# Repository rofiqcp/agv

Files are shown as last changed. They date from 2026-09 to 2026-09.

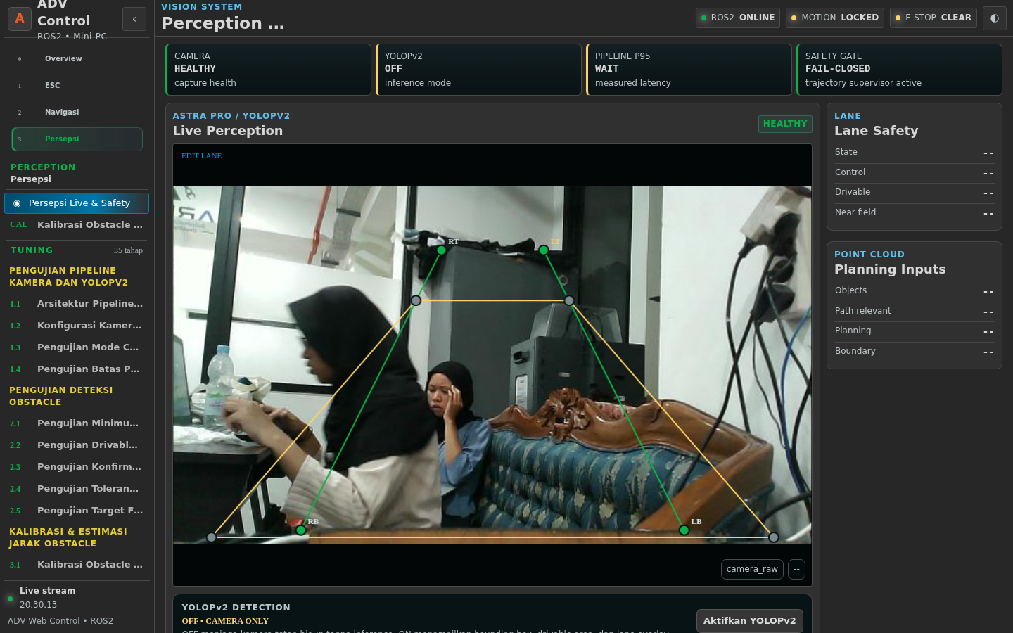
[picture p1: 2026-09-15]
.ui_audit/audit-perception-desktop.png

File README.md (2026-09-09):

# AGV ROS 2 Workspace

Workspace ROS 2 Humble untuk Autonomous Ground Vehicle Ackermann. Root project selalu memakai `AGV_ROOT`; default portable-nya adalah `$HOME/agv`, sehingga username Linux boleh berbeda tanpa mengubah source.

## 1. Clone Pertama Kali

```bash
git clone --recurse-submodules -b v1 https://github.com/rofiqcp/agv.git "$HOME/agv"
cd "$HOME/agv"
git submodule update --init --recursive
```

Jika repository sudah ada:

```bash
cd "$HOME/agv"
git pull --ff-only
git submodule update --init --recursive
```

Firmware STM32F103 berada pada Git submodule `hoverboard-vesc`, sedangkan firmware STM32F411 HMI/gateway berada pada submodule `F4gateway`. Repository AGV mem-pin commit keduanya agar versi hardware reproducible.

## 2. Instalasi Otomatis

Entry point instalasi adalah `install.sh`. Script ini idempotent dan boleh dijalankan ulang.
```bash
cd "$HOME/agv"
./install.sh --with-model --with-browser-qa
```

Default build installer dibatasi untuk menjaga NUC/PC lain tetap responsif:

- CPU maksimal 50% mesin.
- RAM build maksimal 50% RAM fisik.
- `Release` build.
- Compile `j1` untuk translation unit LibTorch/Qt yang berat.
- Package dibuild dari `src/` saja agar repository referensi/submodule tidak dipindai sebagai package ROS.

Opsi penting:

```bash
./install.sh --no-build
./install.sh --build-percent 50 --memory-percent 50
./install.sh --with-model
./install.sh --with-browser-qa
```

Installer memasang dependency ROS/system/Python, `rosdep`, PlatformIO, model opsional, browser QA opsional, dan managed environment block ke `~/.bashrc`.

## 3. Environment Shell
Setelah installer selesai, buka shell baru atau jalankan:

```bash
source ~/.bashrc
```

Managed block AGV menetapkan dan men-source environment berikut:

```text
AGV_ROOT=$HOME/agv
ROS_DISTRO=humble
ROS_DOMAIN_ID=42
```

`$AGV_ROOT/scripts/agv_env.sh` otomatis source `/opt/ros/humble/setup.bash` dan `$AGV_ROOT/install/setup.bash` bila tersedia. Karena itu command ROS dapat dijalankan dari direktori mana pun.

Verifikasi:

```bash
cd /tmp
echo "$AGV_ROOT"
echo "$ROS_DOMAIN_ID"
ros2 pkg prefix navigation
ros2 pkg prefix esc
command -v ros2
```

## 4. Struktur Utama

```text
agv/
├── src/navigation/   # Nav2, localization, EKF, ROS Web, calibration
├── src/perception/   # Astra Pro + YOLOPv2 CPU/GPU
├── src/esc/          # Ackermann command mux + VESC bridge
├── src/stmf4/        # Bridge Mini-PC ↔ STM32F411 ↔ GNSS/VESC
├── hoverboard-vesc/  # Git submodule firmware STM32F103 dual FOC
├── F4gateway/        # Git submodule firmware STM32F411 HMI/gateway
├── models/           # Model YOLOPv2 dan downloader
├── scripts/          # Environment, portability check, browser QA
├── install.sh
└── README.md
```

Folder `build/`, `install/`, dan `log/` adalah hasil lokal dan tidak menjadi source authority.

## 5. Model YOLOPv2

Jika belum memakai `--with-model`:

```bash
cd "$AGV_ROOT/models"
./model.sh
```

Model CPU default:

```text
$AGV_ROOT/models/yolopv2.pt
```

Override path bila diperlukan menggunakan environment `YOLOPV2_PT_PATH` atau `YOLOP_ENGINE_PATH`; source tidak boleh memakai hardcoded `/home/<user>/...`.

## 6. Build dan Test
Gunakan installer untuk build resource-limited yang aman:

```bash
cd "$AGV_ROOT"
./install.sh --build-percent 50 --memory-percent 50
```

Atau untuk incremental build manual setelah environment aktif:

```bash
cd "$AGV_ROOT"
colcon build --base-paths src --symlink-install --executor sequential \
  --allow-overriding perception --cmake-args -DCMAKE_BUILD_TYPE=Release
```

Setelah build:

```bash
source "$AGV_ROOT/install/setup.bash"
colcon test --base-paths src --executor sequential
colcon test-result --verbose
```

Target project adalah 0 warning/error build dan 0 failure test. Portability contract juga dapat dijalankan langsung:

```bash
python3 "$AGV_ROOT/scripts/check_portable_paths.py"
```

## 7. Menjalankan Autonomous Stack
Dari direktori mana pun setelah `source ~/.bashrc`:

```bash
ros2 launch navigation autonomous.launch.py
```

Simpan log runtime:

```bash
ros2 launch navigation autonomous.launch.py | tee "$AGV_ROOT/log/$(date +%Y%m%d_%H%M%S).txt"
```

Untuk QA tanpa risiko command gerak gunakan mode read-only:

```bash
ros2 launch navigation autonomous.launch.py \
  mode:=web web_read_only:=true enable_rviz:=false \
  enable_joystick:=false enable_keyboard:=false
```

ROS Web tersedia di `http://127.0.0.1:5000`.

## 8. Browser QA Playwright

Install sekali lewat:

```bash
cd "$AGV_ROOT"
./install.sh --no-build --with-browser-qa
```

Dengan runtime read-only aktif, jalankan:
```bash
cd "$AGV_ROOT"
node scripts/qa_ros_web_playwright.js
```

QA memeriksa:

- HTTP 200 dan SSE live.
- Tidak ada console/page error.
- Tidak ada HTTP 4xx/5xx atau request failure.
- Tidak ada POST otomatis saat backend read-only.
- Map Navigation terlihat.
- Dua grafik ESC terlihat.
- Frame kamera valid.
- Configuration dan Test workspace dapat dibuka.
- Data Health terisi.
- Layout mobile tidak overflow horizontal.

## 9. Git dan Submodule

Branch utama AGV adalah `v1`. Perubahan firmware harus di-commit/push di repository firmware terlebih dahulu, lalu pointer submodule di repository AGV diperbarui.

```bash
cd "$AGV_ROOT/hoverboard-vesc"
git status
# commit/push STM32F103 bila ada perubahan

cd "$AGV_ROOT/F4gateway"
pio run
git status
# commit/push STM32F411 ke branch v1

cd "$AGV_ROOT"
git add hoverboard-vesc F4gateway .gitmodules
git commit -m "chore: sync firmware submodules"
```

Untuk mengambil commit firmware yang dipin oleh branch AGV saat ini:

```bash
git pull --ff-only
git submodule sync --recursive
git submodule update --init --recursive
```

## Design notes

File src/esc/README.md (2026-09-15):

# ESC Integrated Runtime

Package `esc` sekarang hanya memiliki dua runtime C++:

1. `motor_teleop` — keyboard/gamepad global -> `/cmd_vel/teleop`
2. `esc_ackermann` (`ackermann_controller_server.cpp`) — mux + Ackermann + UART STM

## Priority

1. E-STOP / safety
2. TELEOP active
3. TELEOP release hold (zero command, default 0.50 s)
4. NAV2 final command (`/cmd_vel` by default)
5. IDLE zero

Teleop yang idle terus publish zero **tidak** mengambil alih Nav2 karena ownership manual ditentukan juga oleh `/teleop/active_source`.

## Command chain

```text
keyboard/gamepad -> motor_teleop -> /cmd_vel/teleop ----+
                                                       |
Nav2 controller -> /cmd_vel_nav_raw                    |
 -> velocity_smoother -> /cmd_vel_nav_smoothed         |
 -> NavigationCore/perception/collision -> /cmd_vel ---+-> esc_ackermann
                                                           | mux
                                                           | Ackermann conversion
                                                           | robust UART
                                                           v
                                                          STM32
```

Untuk memakai smoother langsung (bypass final NavigationCore/CollisionMonitor), ubah `nav2_topic` di `config/ackermann.yaml` menjadi `/cmd_vel_nav_smoothed`. Default `/cmd_vel` lebih aman karena merupakan command final setelah safety/collision pipeline.

## Single source of truth limits

`config/teleop.yaml`:

- `speed_max: 1.00` m/s
- `yaw_max_deg_s: 80.0`
- `serial_left_max_deg: 90.0` logical/protocol steering limit (physical wheel angle must be calibrated separately)
- `serial_right_max_rpm: 300.0`

Mapping drive: `1.0 m/s -> 300 RPM`, `0.5 -> 150 RPM`, `-1.0 -> -300 RPM`.

Manual steering preserves the previous teleop behavior: full A/D at the current yaw limit maps to the same real steering degree. Nav2 uses true Ackermann conversion `delta = atan(L * omega / v)` and is then clamped to the same real steering limit.

## STM serial contract

This ROS package expects the robust hoverboard protocol already integrated previously:

- 921600 8N1
- fixed 14-byte frame
- SOF `A5 5A`
- sequence number
- CRC16-CCITT
- command: LEFT real centi-degree + RIGHT deci-RPM
- ACK: measured LEFT real angle + measured RIGHT RPM + status
- firmware watchdog 250 ms

Only `esc_ackermann` opens the serial port. `motor_teleop` contains no UART sender.

## Build

```bash
cd $AGV_ROOT
source /opt/ros/humble/setup.bash
colcon build --symlink-install --packages-select esc navigation
source install/setup.bash
```

Standalone ESC runtime:

```bash
# Default runtime: Mini-PC -> dedicated CH340 USB-UART -> STM32F103/VESC directly.
# F411 remains HMI/GNSS only and never transports actuator bytes.
# VESC Tool desktop connects to localhost TCP 127.0.0.1:65102 through
# vesc_tool_bridge; Web and desktop tooling share the same maintenance authority.
# Nomor /dev/ttyUSBx tidak pernah menjadi authority otomatis.
ros2 launch esc esc.launch.py

# Override hanya untuk commissioning/debug yang disengaja:
# ros2 launch esc esc.launch.py serial_device:=/dev/serial/by-id/<ESC_ID>
```

Full autonomous runtime remains through `navigation/launch/autonomous.launch.py`.

## Steering physical calibration (V10 Part 1)

Nilai protocol STM `-90/0/+90` **bukan** sudut roda fisik. Gunakan halaman **Kalibrasi Steering Fisik** pada GUI navigation untuk menangkap LEFT/CENTER/RIGHT protocol+ACK dan memasukkan hasil ukur sudut roda dalam kiri/kanan. Setelah aktif, `/esc/steering_actual` dan odometri Ackermann menggunakan sudut roda nyata. `serial_left_max_deg` dipertahankan hanya sebagai fallback legacy sebelum commissioning fisik selesai.

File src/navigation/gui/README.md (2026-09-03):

# Autonomous Vehicle Interface — Native C++/Qt5

GUI operator package `navigation` sekarang sepenuhnya native **C++17 + Qt5 + rclcpp**. GUI lama `agv_gui.py` sudah tidak menjadi runtime dan tidak lagi membutuhkan `rclpy` atau `PyQt5`.

## Build

```bash
cd ~/Sistem-Otomasi-Car/Car-MiniPC/ros
rm -rf build/navigation install/navigation
colcon build --packages-select navigation --symlink-install --cmake-clean-cache --event-handlers console_direct+
source install/setup.bash
```

Dependency native yang diperlukan antara lain Qt5 Widgets/Network, yaml-cpp, serta library RViz2 (`rviz_common`, `rviz_rendering`, dan `rviz_default_plugins`). Pada Ubuntu 22.04 + ROS 2 Humble, instalasi `ros-humble-desktop` sudah menyediakannya. Dengan rosdep:

```bash
rosdep install --from-paths src --ignore-src -r -y
```

Jalankan seluruh stack + GUI:

```bash
ros2 launch navigation gui.launch.py
```

GUI saja:

```bash
ros2 run navigation agv_gui
```

## Struktur

- `agv_gui.cpp` — entry translation unit, rclcpp bridge, dan Qt meta-object classes.
- `modules/*.cpp` — modul GUI terpisah untuk YAML/core, reporting, acquisition, steering, ESC/map, kamera, dan main window.
- `agv_gui_specs.hpp` — definisi parameter/configuration pages.
- `agv_experiment_catalog.hpp` — satu-satunya katalog subbab pengujian 4.x untuk Navigasi, Persepsi, dan ESC/FOC.
- `assets/` — aset visual.

ROS dijalankan pada `MultiThreadedExecutor` terpisah sehingga callback sensor tidak memblokir event-loop Qt. Data callback diteruskan ke Qt melalui signal/slot queued connection. Subscription disimpan selama umur bridge sehingga tidak terhapus setelah dibuat.

## Navigasi GUI

Tombol `NAV2 MAP` di kiri atas, tepat di samping `OVERVIEW`, membuka visualisasi Nav2 di panel tengah GUI. Subtab `NAV2 LIVE` menampilkan `/map`, URDF kendaraan, Goal Pose, global path Smac Hybrid-A*, transformed plan MPPI, footprint, dan kandidat trajectory MPPI. Subtab `GROUND TRUTH` mempertahankan kanvas PGM/OSM, tabel target, dan akuisisi ground truth lama.

Renderer RViz/OGRE dibuat secara lazy saat `NAV2 MAP` dibuka dan dihentikan saat halaman ditinggalkan. Global/local costmap default OFF karena map UNDIP besar; operator dapat mengaktifkannya dari checkbox. Kandidat MPPI tetap aktif dengan sampling visual 1/20 rollout, tanpa mengubah 1000 sampel optimasi controller.

Tombol `☰` kiri atas membuka **satu floating menu**. Menu hanya mempunyai tiga tab utama: **Navigasi**, **Persepsi**, dan **ESC**. Di setiap tab, subbab 4.1, 4.2, dst. serta leaf 4.x.x dibangun langsung dari `agv_experiment_catalog.hpp`. Tidak ada lagi panel `Tools lama` dan tidak ada tree BAB IV permanen yang memenuhi sidebar.

Klik leaf 4.x.x merutekan ke workspace akuisisi existing yang sama, bukan membuat widget duplikat. Pilihan subsystem/leaf terakhir disimpan ke `gui.yaml` (`navigation_menu.active_subsystem` dan `navigation_menu.active_leaf`) sehingga session berikutnya kembali ke pengujian terakhir.

Parameter panel kiri tetap memakai YAML sebagai source of truth dengan autosave atomik. GUI juga mempertahankan vehicle-authority synchronization, Config-vs-Runtime audit, MPPI A/B/C sweep, stationary IMU/GNSS capture, COG qualification, GNSS fusion controls, rosbag, CPU/GPU profile, snapshot konfigurasi, CSV/PNG export, dan metadata SHA-256.

## Pelaporan

Setiap CSV menghasilkan sidecar `.meta.json` yang berisi session/experiment metadata, snapshot SHA-256 konfigurasi, serta statistik numerik. Kolom bernama `error` atau `residual` juga mendapatkan RMSE, mean absolute error, dan maximum absolute error.

## Catatan runtime

Perubahan YAML tidak otomatis berarti node yang sudah berjalan telah menerima nilai baru. Gunakan **Verify Runtime** dan restart/live-apply node terkait sebelum merekam pengujian. Tutup GUI akan menghentikan launch pada `gui.launch.py`, sehingga autonomous stack tidak tertinggal berjalan tanpa HMI.

Panduan visual, topik, penggunaan Goal Pose, dan diagnosis tersedia di `docs/GUI_NAV2_EMBEDDED.md`.

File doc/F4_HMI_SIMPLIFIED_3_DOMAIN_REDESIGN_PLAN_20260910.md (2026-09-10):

# F4 HMI Simplified 3-Domain Redesign Plan

Tanggal: 2026-09-10
Target: STM32F411 + ILI9341 320x240 + XPT2046
Sumber data: `/home/sirobo/agv/src`, `/home/sirobo/agv/F4gateway`, `/home/sirobo/agv/hoverboard-vesc`

## 1. Tujuan

Redesain HMI menjadi sederhana untuk operator, tetapi tetap kuat untuk commissioning dan diagnostics.
Menu utama hanya berisi HOME, ESC, PERSEPSI, dan NAVIGASI.
SYSTEM tidak tampil sebagai menu utama; health penting tetap terlihat sebagai indikator global.
Diagnostics teknis dipertahankan melalui Service Mode agar tidak ada fungsi yang hilang.

Prinsip utama:
- satu layar = satu tujuan;
- maksimal tiga kartu besar per halaman;
- BACK / LEFT / RIGHT selalu pada posisi yang sama;
- icon + label wajib pada setiap kartu;
- data live hanya yang membantu keputusan operator;
- parameter berbahaya tidak diedit langsung dari layar umum;
- test motion menggunakan hold-to-run + release-to-stop;
- stale/offline/fault harus terlihat jelas.

## 2. Hierarki layar

```text
SPLASH
  -> HOME
      -> MAIN MENU
          -> ESC
          -> PERCEPTION
          -> NAVIGATION
```
## 3. HOME

HOME tidak menjadi menu; HOME adalah ringkasan kendaraan.
Hanya tiga data utama ditampilkan besar:
1. SPEED — `speedKmh` / `driveActualMps`.
2. VEHICLE STATE — READY / STOPPED / RUNNING / FAULT, dengan E-STOP override merah.
3. POWER / VBUS — tegangan supply/VESC bus dan warning undervoltage/overvoltage.

Tambahan kecil yang tidak dianggap kartu data:
- chip kecil AUTO/MANUAL + active source;
- indikator ESC, PER, NAV berupa tiga dot kecil READY/WARN/FAULT;
- indikator link F4↔ROS dan F4↔F103 kecil;
- jam/data age tidak perlu memenuhi layar.

Interaksi HOME:
- hanya satu tombol besar `MENU` di bawah;
- tidak ada carousel;
- tidak ada tombol setting;
- E-STOP selalu menjadi banner prioritas tertinggi.

Acceptance HOME:
- dapat dibaca <1 detik;
- tidak lebih dari tiga angka/status besar;
- operator langsung tahu: bergerak seberapa cepat, kendaraan dalam state apa, dan power supply sehat atau tidak.

## 4. MAIN MENU

Header: tombol `HOME` di kiri atas.
Isi: tiga kartu besar penuh lebar efektif:
- ESC — steering wheel + bolt;
- PERSEPSI — camera/eye;
- NAVIGASI — route/map pin.

Tidak ada SYSTEM card pada menu utama.
## 5. Layout standar domain

Setiap root ESC / PERSEPSI / NAVIGASI memakai layout identik.

Top navigation bar sekitar 34 px:
- kiri: `BACK`;
- tengah: `LEFT`;
- kanan: `RIGHT`;
- judul domain kecil berada di antara/di bawah kontrol tanpa menambah tombol.

Area kartu dari sekitar y=48 sampai y=218:
- tiga kartu submenu berdampingan;
- setiap kartu sekitar 98x158 px efektif;
- icon besar di bagian atas;
- label 1–2 baris di bawah;
- status dot kecil pada pojok kartu: green/yellow/red/gray;
- page indicator kecil `1/3`, `2/3`, dst.

LEFT/RIGHT menggeser satu kelompok berisi tiga submenu, bukan satu card.
Wrap-around boleh diaktifkan: page terakhir RIGHT kembali ke page pertama.
BACK kembali satu level dan tidak mengubah state kendaraan.

## 6. Detail page standard

Ketika kartu dipilih, masuk ke detail page.
Detail page tetap memakai kontrol atas `BACK / LEFT / RIGHT`.
LEFT/RIGHT di detail berganti view data dalam fungsi yang sama.
Maksimal tiga metric primer besar per view.
Bar status tipis menampilkan freshness, source, dan fault.

Action/test hanya muncul bila memang tersedia dan aman.
Read-only menjadi default; edit/test harus eksplisit.
Parameter yang dapat menggerakkan aktuator menggunakan confirmation/gate dan dead-man.
## 7. ESC — struktur submenu

ESC dibuat 4 halaman, masing-masing tepat tiga kartu.

### ESC page 1/4 — operasi dasar
1. `ESC OVERVIEW`
2. `OPERATOR MODE`
3. `STEERING`

### ESC page 2/4 — aktuator dan FOC
4. `DRIVE`
5. `FOC / POWER`
6. `MOTOR TELEMETRY`

### ESC page 3/4 — sensor dan commissioning
7. `ENCODER`
8. `CALIBRATION`
9. `COMMUNICATION`

### ESC page 4/4 — robustness
10. `FAULT & SAFETY`
11. `PERFORMANCE`
12. `MANUAL TEST`

Semua kartu mempunyai icon berbeda dan status dot.
Tidak ada parameter tuning berbahaya langsung pada root card.
### 7.1 ESC OVERVIEW
View A — motion:
- vehicle speed;
- drive target vs actual;
- steering target vs actual.

View B — motor summary:
- right motor eRPM / mechanical RPM;
- VESC connected/fresh;
- current fault code.

View C — control readiness:
- ESC feedback valid;
- encoder ready;
- active command source: TELEOP / HMI / NAV2 / IDLE.

Tidak ada test pada overview.

### 7.2 OPERATOR MODE
Tampilan:
- current mode AUTO/MANUAL;
- active source;
- motion-ready gate;
- E-STOP / safety gate.

Action:
- ganti AUTO <-> MANUAL hanya ketika speed ~0 dan tidak E-STOP;
- perubahan membutuhkan ACK dari ROS bridge;
- timeout/failure harus mengembalikan nilai lama.
### 7.3 STEERING
View A — live:
- target angle deg;
- actual angle deg;
- tracking error deg.

View B — steering state:
- calibrated / homed / encoder synced;
- raw encoder / logical position;
- sensor/FOC mode.

View C — limits:
- physical left/right limit;
- operational limit;
- center/deadband state.

Safe test:
- selectable test angle 5–30 deg;
- HOLD LEFT / HOLD CENTER / HOLD RIGHT;
- release selalu STOP/HOLD;
- hanya MANUAL + zero speed + fresh encoder + no E-STOP.

### 7.4 DRIVE
View A — live:
- drive target m/s;
- drive actual m/s;
- eRPM / mechanical RPM.

View B — calibration:
- drive scale;
- eRPM per m/s;
- odometry calibration scale.
View C — drive safety:
- max commanded speed;
- watchdog state;
- perception/autonomy gate.

Safe test:
- manual speed selector 10–50%;
- HOLD FORWARD / HOLD REVERSE;
- release/slide-out -> current/RPM command zero;
- hard timeout tetap aktif di F4 dan F103.

### 7.5 FOC / POWER
View A — power:
- Vbus;
- motor current / input current;
- duty cycle.

View B — FOC current:
- Iq;
- Id;
- current limit.

View C — thermal/fault:
- MOS temperature;
- motor temperature bila tersedia;
- active VESC fault.

Data diambil dari VESC `COMM_GET_VALUES(_SELECTIVE)`.
F4 bridge perlu diperluas karena telemetry F4 saat ini belum membawa semua field ini.
Tidak ada direct current/duty test pada operator page.
### 7.6 MOTOR TELEMETRY
View A — LEFT steering motor:
- RPM/eRPM;
- position;
- duty/current.

View B — RIGHT drive motor:
- RPM/eRPM;
- Vbus/current;
- duty/fault.

View C — comparison:
- left/right fault state;
- link freshness;
- telemetry age.

### 7.7 ENCODER
View A — steering encoder:
- raw count;
- logical steering deg;
- synced/configured state.

View B — diagnostics:
- edge A / edge B count;
- invalid transition / error count;
- direction/inversion.

View C — rotor relationship:
- encoder mechanical angle;
- observer electrical angle;
- encoder-observer / PID error.

Read-only by default. Encoder detect/align hanya melalui commissioning gate.
### 7.8 CALIBRATION
View A — steering calibration summary:
- calibrated/homed;
- measured span / safe span;
- current center position.

View B — physical mapping:
- left physical reference;
- center reference;
- right physical reference.

View C — drive calibration:
- wheel radius;
- eRPM per m/s;
- odometry scale.

Action dibatasi:
- `HOME STEERING` dan `SET CENTER` hanya saat kendaraan idle;
- calibration wizard menggunakan langkah eksplisit dan confirmation;
- parameter raw FOC/ADC tidak diedit dari operator HMI.

### 7.9 COMMUNICATION
View A — F4↔F103:
- connected/fresh;
- UART RX/TX age;
- error/drop/recovery counters.

View B — ROS↔F4:
- HMI connected;
- command/telemetry age;
- deferred queue/drop state.

View C — maintenance ownership:
- RUNTIME / VESC TOOL / PYTHON owner;
- maintenance active;
- route transition/safe-stop state.
### 7.10 FAULT & SAFETY
View A — active faults:
- VESC fault code/text;
- E-STOP state;
- safety switch state.

View B — electrical limits:
- under/over-voltage status;
- over-current status;
- temperature limit status.

View C — command safety:
- command watchdog;
- active source freshness;
- autonomy/perception gate.

Action yang diizinkan hanya `CLEAR/ACK` bila fault memang recoverable.
Tidak ada bypass safety dari layar.

### 7.11 PERFORMANCE
View A — control timing:
- command loop rate;
- feedback age;
- max service latency.

View B — F103 realtime:
- ISR max/budget;
- GET_VALUES latency;
- watchdog/reset counters.

View C — F4 gateway:
- service p95/p99/max;
- stack headroom;
- SPI/UART error counters.

### 7.12 MANUAL TEST
Dedicated commissioning screen, bukan metric page biasa.
Controls: LEFT / FORWARD / STOP / RIGHT / REVERSE.
Speed dan steering-angle preset ditampilkan di layar.
Semua motion action harus hold-to-run; STOP immediate; release/timeout/freshness-loss menghasilkan STOP.
## 8. PERSEPSI — struktur submenu

PERSEPSI dibuat 3 halaman, masing-masing tiga kartu.

### PERSEPSI page 1/3 — sumber dan hasil utama
1. `PER OVERVIEW`
2. `CAMERA`
3. `DETECTION`

### PERSEPSI page 2/3 — pemahaman area kendaraan
4. `LANE`
5. `DRIVABLE AREA`
6. `OBSTACLE`

### PERSEPSI page 3/3 — kualitas dan commissioning
7. `PERFORMANCE`
8. `CALIBRATION`
9. `PER TEST`

F4 tidak perlu menampilkan video kamera penuh; bandwidth serial, RAM dan fungsi operator tidak membutuhkannya.
HMI menampilkan health/hasil perception yang actionable.

### 8.1 PER OVERVIEW
View A:
- camera connected/healthy;
- perception ready;
- inference ON/OFF.

View B:
- lane safety state;
- drivable clear/valid;
- obstacle detected + nearest distance.

View C:
- pipeline FPS;
- data freshness;
- control/advisory state.
### 8.2 CAMERA
View A — camera health:
- connected;
- healthy;
- current FPS.

View B — capture config summary:
- resolution;
- requested camera FPS;
- backend CPU/GPU / inference state.

View C — stream diagnostics:
- frame age;
- dropped/failed frame count bila tersedia;
- hotplug/recovery state.

Action aman:
- inference ON/OFF boleh melalui ACK;
- restart camera tidak ditempatkan sebagai tombol satu-tap; service confirmation diperlukan.

### 8.3 DETECTION
View A — nearest object:
- class;
- distance m;
- confidence.

View B — detection summary:
- number of objects;
- ROI-valid objects;
- nearest obstacle class/distance.

View C — tracking:
- active track count;
- missed/stale state;
- detection data age.

F4 bridge perlu ditambah field confidence/count bila belum tersedia.
### 8.4 LANE
View A — lane state:
- lane safety state;
- center offset;
- confidence.

View B — geometry:
- near/far lookahead;
- estimated road width;
- lane center correction.

View C — control:
- lane-control state;
- requested steering correction;
- command/data freshness.

### 8.5 DRIVABLE AREA
View A:
- valid / invalid;
- drivable clear / blocked;
- drivable fraction.

View B:
- nearest boundary/clearance;
- left/right usable corridor;
- far lookahead.

View C:
- lane constraint active;
- ROI/config status;
- source age.

Read-only untuk operator.

### 8.6 OBSTACLE
View A:
- nearest obstacle class;
- forward distance;
- lateral offset.

View B:
- blocked/clear state;
- number of obstacle points/tracks;
- ROI-valid state.
View C:
- confirm/release frame counters;
- obstacle data age;
- perception advisory output state.

### 8.7 PERFORMANCE
View A:
- pipeline FPS;
- inference latency ms;
- frame age.

View B:
- backend CPU/GPU;
- inference enabled;
- dropped/recovery count bila tersedia.

View C:
- publish/update rates;
- lane metric age;
- obstacle metric age.

### 8.8 CALIBRATION
View A — obstacle distance calibration:
- selected class/model;
- scale;
- bias.

View B — lane corridor calibration:
- camera height/pitch;
- left/right corridor offsets;
- safety margin.

View C — status:
- calibration source/version;
- saved/unsaved state;
- current ROI valid.

HMI operator hanya melihat summary. Parameter geometrik detail tetap di ROS Web karena lebih cocok untuk layar besar dan visual overlay.

### 8.9 PER TEST
Test yang aman:
- camera heartbeat test;
- inference ON/OFF test;
- lane freshness test;
- obstacle freshness test;
- publish/bridge ACK test.

Tidak boleh menggerakkan kendaraan dari PER TEST.
## 9. NAVIGASI — struktur submenu

NAVIGASI dibuat 4 halaman, masing-masing tiga kartu.

### NAVIGASI page 1/4 — state utama
1. `NAV OVERVIEW`
2. `LOCALIZATION`
3. `GNSS`

### NAVIGASI page 2/4 — estimator/sensor
4. `IMU / MAG`
5. `EKF`
6. `ODOMETRY`

### NAVIGASI page 3/4 — operasi autonomous
7. `MISSION`
8. `NAV2`
9. `SAFETY`

### NAVIGASI page 4/4 — planning dan diagnostic
10. `COSTMAP`
11. `PATH / CONTROL`
12. `NAV TEST`

### 9.1 NAV OVERVIEW
View A:
- localization READY/DEGRADED/FAULT;
- Nav2 READY/NOT READY;
- navigation status IDLE/NAVIGATING/ARRIVED/FAILED.

View B:
- active target;
- distance/pose progress bila tersedia;
- current vehicle speed.

View C:
- GNSS age/fix;
- IMU health;
- autonomy motion gate.
### 9.2 LOCALIZATION
View A:
- localization state;
- map pose freshness;
- heading deg.

View B:
- local EKF status;
- global EKF status;
- pose source priority.

View C:
- position covariance/accuracy summary bila di-bridge;
- yaw confidence summary;
- stale/fault reason.

### 9.3 GNSS
View A — fix:
- FIX type;
- satellite count;
- HACC m.

View B — position:
- latitude;
- longitude;
- heading.

View C — quality:
- HDOP;
- GNSS age;
- connected/state.

Tidak ada edit receiver port/baud pada operator HMI.

### 9.4 IMU / MAG
View A — IMU:
- connected;
- gyro Z;
- yaw/heading.

View B — magnetometer:
- connected;
- field/heading summary bila tersedia;
- sensor freshness.

View C — consistency:
- GNSS heading vs IMU heading;
- yaw-rate state;
- disagreement warning.
### 9.5 EKF
View A — EKF local:
- status;
- odom freshness;
- local pose/yaw summary.

View B — EKF global:
- status;
- map pose freshness;
- global position summary.

View C — fusion health:
- GNSS contribution valid;
- IMU contribution valid;
- innovation/covariance warning summary bila tersedia.

### 9.6 ODOMETRY
View A:
- linear speed;
- yaw rate;
- steering actual.

View B:
- odom X/Y;
- yaw;
- odom age.

View C:
- raw ESC speed vs filtered odometry speed;
- tracking error;
- drive calibration scale.

Read-only; calibration perubahan dilakukan dari ESC CALIBRATION atau ROS Web.

### 9.7 MISSION
View A — waypoint browser:
- selected waypoint;
- saved/not saved;
- name.

View B — active mission:
- active target;
- NAV status;
- goal freshness.

View C — current pose capture:
- current X/Y/yaw;
- GNSS lat/lon if valid;
- waypoint storage state.
Mission actions:
- `SAVE CURRENT` hanya saat localization fresh;
- `GO` membutuhkan confirmation dan readiness gate;
- `STOP NAV` selalu tersedia dan immediate;
- nama waypoint tidak diedit lewat keyboard HMI kecil; gunakan default/nama dari ROS Web.

### 9.8 NAV2
View A — stack readiness:
- Nav2 ready;
- lifecycle/stack state summary;
- active navigation state.

View B — planner/controller:
- planner active;
- controller active;
- smoother active.

View C — command flow:
- Nav2 cmd freshness;
- perception advisory freshness;
- ESC mux source.

Tidak ada parameter Nav2 kompleks yang diedit langsung dari F4 HMI.

### 9.9 SAFETY
View A:
- E-STOP;
- NEO3 safety switch;
- autonomy motion allowed.

View B:
- lane safety state;
- obstacle blocked state;
- perception advisory state.

View C:
- ESC watchdog;
- cmd_vel freshness;
- localization freshness.

Safety page tidak menyediakan bypass/override.
### 9.10 COSTMAP
View A:
- local costmap ready;
- obstacle layer freshness;
- footprint/robot radius status.

View B:
- obstacle point age/count summary;
- clearing point age/count summary;
- inflation/blocked summary.

View C:
- costmap stale/fault reason;
- source perception status;
- Nav2 consumption state.

### 9.11 PATH / CONTROL
View A — planner:
- SMAC planner state;
- current path valid;
- replan/failure count bila tersedia.

View B — controller:
- MPPI state;
- current linear/angular command;
- controller age.

View C — smoother/tracking:
- smoother state;
- target vs actual speed;
- steering/yaw tracking error.

### 9.12 NAV TEST
Read-only test sequence tanpa motion sebagai default:
- GNSS freshness;
- IMU freshness;
- EKF local/global ready;
- Nav2 lifecycle ready;
- costmap input fresh;
- planner/controller availability.

Optional motion test tidak digabung ke NAV TEST; motion tetap hanya melalui controlled MANUAL TEST ESC.
## 10. Service Mode — tidak tampil di MAIN MENU

Fungsi SYSTEM lama tidak dihapus.
Akses Service Mode hanya jika kendaraan STOPPED, misalnya long-press MENU/HOME 3 detik atau command service dari USB.

Service Mode memakai 10 kartu yang sudah disiapkan:
1. SYSTEM HEALTH
2. IO PIN MONITOR
3. DISPLAY PINS
4. LINK DIAGNOSTICS
5. ERROR COUNTERS
6. SPI BUS
7. UART STATUS
8. POWER STATUS
9. TOUCH PANEL
10. TFT TEST

TFT TEST, SPI verify/recovery, dan maintenance berat tetap memakai motion-safe gate.
Operator normal tidak melihat halaman ini sehingga main menu tetap hanya tiga domain.

## 11. Strategy asset/logo

Setiap kartu wajib berisi icon + label.
Jangan simpan tile 100x150 full RGB565 untuk setiap menu karena flash akan boros.
Gunakan icon-only 48–56 px dengan transparent/palette mask; label dirender native oleh HMI.

Target asset:
- 4 top assets: HOME/MENU, ESC, PERSEPSI, NAVIGASI;
- 12 ESC icons;
- 9 PERSEPSI icons;
- 12 NAVIGASI icons;
- 10 Service Mode icons.

Semua icon memakai palette navy/cyan/cream yang sama.
Selected card memakai cyan border; warning amber; fault red; disabled gray.
## 12. Data model baru di F4gateway

Jangan menambah ratusan global variable terpisah.
Pisahkan telemetry menjadi typed domain structs:
- `HomeTelemetry`;
- `EscTelemetry`;
- `PerceptionTelemetry`;
- `NavigationTelemetry`;
- `ServiceTelemetry`.

Setiap struct mempunyai:
- nilai aktual;
- validity bit;
- source timestamp/age;
- status READY/WARN/FAULT/STALE.

ROS bridge mengirim data yang sudah dinormalisasi; F4 tidak parsing JSON kompleks.
Serial update tetap incremental dan change-driven.

Tambahan ESC bridge yang dibutuhkan:
- Vbus, duty, motor/input current, Iq/Id;
- MOS/motor temperature;
- VESC fault code;
- left/right motor values;
- encoder raw/sync/homing/calibration state;
- ISR/GET_VALUES timing summary.

Tambahan perception bridge:
- object confidence/count;
- lane center offset/confidence;
- drivable fraction/clearance;
- nearest obstacle lateral offset;
- inference/pipeline latency and ages.

Tambahan navigation bridge:
- map/odom pose summary;
- covariance/accuracy summary;
- costmap/planner/controller state;
- path/controller freshness.
## 13. UI state machine

Gunakan state eksplisit, bukan menu-parent logic yang semakin bercabang:
- `HOME`;
- `MAIN_MENU`;
- `DOMAIN_MENU`;
- `DETAIL_VIEW`;
- `SERVICE_MENU`;
- `SERVICE_DETAIL`.

State menyimpan:
- active domain;
- domain page index;
- selected card;
- detail view index;
- edit/test state;
- touch generation id.

Descriptor data-driven per card:
- ID;
- label;
- icon asset;
- status provider;
- number of detail views;
- action capability flags.

Dengan descriptor ini LEFT/RIGHT dan pagination tidak memakai switch besar berulang.
Card yang belum mendapat data tidak dihapus; tampil `N/A` atau `STALE`.

## 14. Touch behavior

HOME: hanya MENU.
MAIN MENU: HOME + tiga domain cards.
DOMAIN MENU: BACK + LEFT + RIGHT + tiga cards.
DETAIL: BACK + LEFT + RIGHT untuk cycle data view.

Semua tap commit-on-release dan slide-cancel.
Motion test menggunakan long/hold action, tidak tap-latched.
Page change menaikkan touch generation agar release lama tidak mengeksekusi action baru.
## 15. Rendering dan refresh

Gunakan renderer native F4 yang sekarang sudah optimized; jangan migrasi ke LVGL penuh.
Dirty rendering dibagi per region:
- top controls;
- card 0;
- card 1;
- card 2;
- detail metric 0/1/2;
- fault/status strip.

Perubahan telemetry identik = 0 physical paint bytes.
Icon hanya redraw bila card/page/status visual berubah.
Metric hanya redraw bila text/color berubah.
Target full page transition tetap <150 ms pada validated 24 MHz SPI.
Target telemetry incremental <25 ms ideal dan <50 ms maksimum.

## 16. Visual language

Background: navy gelap.
Cards: cream/off-white untuk kontras tinggi.
Primary accent: cyan.
READY: green; WARNING/STALE: amber; FAULT/E-STOP: red; disabled: gray.

Card status tidak hanya berdasarkan warna:
- `OK` / `WARN` / `FAULT` / `STALE` micro-label;
- dot/icon status;
- sehingga tetap terbaca tanpa mengandalkan warna saja.

Label card maksimal dua baris.
Angka primer menggunakan font terbesar yang masih aman untuk 320x240.
Tidak ada dekorasi yang mengurangi area data.

## 17. Klasifikasi fungsi

READ ONLY:
- semua live telemetry, diagnostics, status sensor, planning state.

EDIT SAFE:
- AUTO/MANUAL;
- manual speed preset;
- steering test angle;
- perception inference ON/OFF.

ACTION GUARDED:
- save/go waypoint;
- steering home/set center;
- manual motion test;
- clear recoverable fault.

SERVICE ONLY:
- raw FOC tuning;
- detect motor/encoder/hall;
- TFT/SPI maintenance;
- raw pin tests;
- firmware/DFU.
## 18. Tahap implementasi

### Tahap 0 — baseline
- simpan benchmark build/RAM/flash;
- capture current screenshots/menu tree;
- pastikan branch/status bersih atau diff terdokumentasi;
- jalankan semua self-check existing.

### Tahap 1 — navigation skeleton
- buat state machine HOME / MAIN / DOMAIN / DETAIL / SERVICE;
- implement HOME baru;
- implement MAIN MENU 3-domain;
- implement top BACK/LEFT/RIGHT;
- implement three-card pagination.

### Tahap 2 — asset pipeline
- normalisasi icon menjadi ukuran seragam;
- convert ke compact palette/mask asset;
- buat asset registry;
- uji flash footprint dan render time.

### Tahap 3 — ESC
- implement 12 cards + detail views;
- tambah normalized ESC telemetry bridge;
- implement safe edit/test gates;
- hardware test F4↔F103/VESC tanpa mengubah pin.

### Tahap 4 — PERSEPSI
- implement 9 cards + detail views;
- tambah metric bridge yang belum tersedia;
- uji stale/camera disconnect/inference OFF.

### Tahap 5 — NAVIGASI
- implement 12 cards + detail views;
- tambah EKF/odom/Nav2 summary bridge;
- uji GNSS loss, EKF degraded, Nav2 unavailable, cancel navigation.
### Tahap 6 — Service Mode
- pindahkan SYSTEM lama ke Service Mode;
- tambah 10 service cards;
- akses hanya saat STOPPED;
- pertahankan motion-safe gate untuk TFT/SPI/maintenance.

### Tahap 7 — robustness
- stale/freshness di semua domain;
- disconnect/reconnect ROS/F103/camera/GNSS;
- E-STOP selama rendering/test;
- touch slide-cancel/generation invalidation;
- 500+ page transition stress.

### Tahap 8 — cleanup
- hapus menu enum/renderer/card lama yang tidak dipakai;
- hapus duplicate icon/asset;
- hapus compatibility path yang tidak lagi diperlukan;
- rapikan naming dan descriptor;
- update README/test/mockup agar sesuai UI baru.

### Tahap 9 — final validation
- build release;
- flash hardware;
- test HOME/MAIN/semua carousel/detail;
- test action guard dan dead-man;
- test UART/SPI error/drop;
- ukur full-page dan incremental render;
- verifikasi RAM/flash/stack margin;
- final audit no dead code dan no unreachable menu.

## 19. Acceptance criteria

- HOME hanya punya 3 data besar + satu MENU button.
- MAIN MENU hanya HOME + ESC + PERSEPSI + NAVIGASI.
- setiap domain root menampilkan tepat tiga card pada satu waktu.
- BACK/LEFT/RIGHT selalu di atas dan konsisten.
- semua card punya logo representatif + label.
- semua submenu reachable dan dapat kembali tanpa loop/menu buntu.
- stale data tidak pernah ditampilkan seperti live/READY.
- action berbahaya tidak mungkin berjalan saat motion gate gagal.
- release touch selalu menghentikan manual motion.
- no SPI/UART regression dan no unexpected reset.
- zero telemetry change menghasilkan zero unnecessary repaint.
- tidak ada overlap/out-of-bounds pada 320x240.
- tidak ada dead code renderer/menu lama setelah migrasi selesai.

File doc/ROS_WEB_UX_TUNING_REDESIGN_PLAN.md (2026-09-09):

# ROS Web UX, Overlay, Help, dan Tuning Redesign Plan

**Project:** AGV ROS 2 Humble  
**Target:** `/home/sirobo/agv/src/navigation/web`  
**Referensi lokal:** `/home/sirobo/agv/esc/vesc_tool` dan `/home/sirobo/agv/ardupilot/MissionPlanner`  
**Tanggal audit:** 2026-09-10  
**Status:** PLAN / belum mengubah implementasi ROS Web  

---

## 1. Tujuan

Redesign ROS Web harus menghasilkan engineering console yang tetap kuat untuk commissioning, tetapi tidak membuat operator bingung karena terlalu banyak panel, tab semu, parameter mentah, atau kontrol yang tampak ganda.

Target utamanya:

1. Tidak ada panel yang menimpa panel lain secara tidak sengaja.
2. Tidak ada fungsi yang tampil dua kali tanpa alasan yang jelas.
3. Secondary tab menjadi **true workspace tab**, bukan hanya scroll-to-anchor.
4. Tuning mengikuti alur kerja manusia: **pilih tujuan → ubah parameter → lihat efek → validasi → simpan**.
5. Operator baru dapat memahami fungsi parameter/box/tombol tanpa membaca source code.
6. Engineer tetap mendapat akses lengkap ke YAML, runtime state, raw telemetry, trial, graph, dan expert parameter.
7. Tampilan mengambil pola terbaik VESC Tool dan MissionPlanner tanpa menyalin kepadatan/legacy UX keduanya.
8. Semua perubahan visual dibuktikan dengan automated overlap test dan screenshot regression.

## 2. Scope Audit yang Sudah Dilakukan

Source yang diperiksa:

- `src/navigation/web/static/index.html`
- `src/navigation/web/static/app.js`
- `src/navigation/web/static/styles.css`
- `src/navigation/web/static/vesc_mp_theme.css`
- struktur VESC Tool, terutama `configparams.*`, `widgets/paramedit*`, `widgets/helpdialog.*`, `startupwizard.*`, dan halaman connection/motor.
- struktur MissionPlanner, terutama `ConfigRawParams`, `ParameterMetaDataRepository`, `MavlinkNumericUpDown`, `MavlinkComboBox`, calibration pages, dan `ParamCompare`.

Catatan audit runtime:

- Saat audit ini `localhost:5000` **tidak sedang listen**, sehingga tidak ada klaim bahwa screenshot runtime aktif telah diverifikasi.
- Audit visual saat ini berasal dari DOM/CSS/JS source yang benar-benar terpasang.
- Plan implementasi mewajibkan browser QA saat server aktif sebagai acceptance gate.

### 2.1 Angka penting dari source sekarang

- `index.html`: 764 ID diperiksa dan **tidak ada duplicate ID**.
- `page-esc`: sekitar 13 panel, 43 button, 16 input dalam satu page.
- `page-experiments`: sekitar 12 panel, 25 button, 11 input sebelum field tuning dinamis dirender.
- `page-perception`: 8 panel, belum termasuk detail dinamis.
- `styles.css` mengulang selector `.topbar` sampai 10 kali.
- Sekitar **250 selector yang sama** didefinisikan di `styles.css` dan di-override lagi oleh `vesc_mp_theme.css`.

## 3. Temuan Utama: Penyebab UI Terasa Double / Overlay / Useless

### 3.1 Tab sekunder masih tab semu — PRIORITAS P0

`WORKSPACE_TABS` mempunyai banyak action `anchor:<page>:<section>`. `activateWorkspaceTab()` hanya membuka page lalu menjalankan `scrollIntoView()`.

Akibatnya:

- klik `Perception > Detection` tidak membuat Detection menjadi workspace tunggal;
- Camera, Lane, Planning, Calibration, Performance, Detection, Safety, dan Evidence tetap berada dalam DOM/layout page yang sama;
- klik tab memberi persepsi seperti pindah halaman, tetapi sebenarnya hanya berpindah posisi scroll;
- semakin banyak feature ditambahkan, page semakin panjang dan terasa seperti konten ganda.

**Keputusan:** semua workspace tab harus memakai state `activePane`, dan hanya pane yang relevan yang visible. Scroll-to-anchor hanya boleh dipakai untuk link dokumentasi, bukan navigasi primer.

### 3.2 CSS bertumpuk antar-generasi — PRIORITAS P0

Saat ini `styles.css` berisi banyak revisi append-only, kemudian `vesc_mp_theme.css` melakukan override besar lagi. Contoh class yang berkali-kali didefinisikan: `.topbar`, `.sidebar`, `.content`, `.panel`, `.map-layout`, `.config-workbench`, `.tuning-field`, `.rviz-stage`, dan `.workspace-tabs`.

Risikonya:

- layout final ditentukan oleh urutan file, bukan satu design contract;
- breakpoint lama dan baru dapat saling mengalahkan;
- perubahan kecil berpotensi memunculkan overlap pada resolusi lain;
- developer sulit mengetahui declaration mana yang authoritative.

**Keputusan:** setelah UI target stabil, consolidate menjadi token + layout + component + page layer yang jelas. Tidak boleh ada “V2/V3/V5 final override” sebagai mekanisme desain permanen.

### 3.3 Overlay yang memang benar vs overlay yang harus dibuang

**Overlay yang sah dan harus dipertahankan:**

- `perceptionCalOverlay` di atas camera frame, karena fungsi utamanya memang drag calibration.
- RViz/map layer controls di atas map, bila compact/collapsible.
- toast, confirm modal, dan mobile sidebar backdrop.
- context visual Map/Camera/ESC yang memakai satu viewport, **asal hanya satu pane active**.

**Syarat overlay yang sah:**

- inactive layer wajib `display:none` atau `visibility:hidden + pointer-events:none`;
- inactive layer tidak boleh menerima focus/tab;
- z-index harus berasal dari skala token, bukan angka acak;
- canvas calibration hanya menerima pointer saat calibration mode aktif;
- placeholder tidak boleh berada di atas image setelah frame valid;
- overlay harus mengikuti bounding rect media yang sebenarnya, termasuk letterbox/object-fit.

**Overlay/stacking yang harus dihilangkan atau direstruktur:**

- seluruh section dalam domain yang tetap visible saat secondary tab lain dipilih;
- dua atau lebih control bars yang menawarkan action sama pada satu context;
- sticky workspace tabs yang dapat bertabrakan dengan topbar saat breakpoint mengubah tinggi topbar;
- layer lama yang hanya disembunyikan oleh CSS override generasi terbaru tetapi masih menjadi struktur utama.

### 3.4 Hidden legacy navigation tetap menjadi technical debt

`legacy-domain-switch` memang `hidden`, tetapi masih berada di DOM. Ini bukan visual bug saat ini, namun menambah dua sumber navigasi dan state yang harus dipelihara.

**Keputusan:** setelah domain sidebar baru proven, hapus markup/event path legacy, jangan hanya menyembunyikannya.

### 3.5 Tuning page terlalu banyak tanggung jawab

Saat ini satu page tuning/experiments memuat sekaligus:

- commissioning roadmap;
- phase tabs + family tabs;
- chapter browser/search;
- selected-test header;
- procedure guide;
- preflight safety;
- run identity/recorder;
- live graph;
- YAML parameter editor;
- context visual;
- perception-specific wizard;
- result table;
- trial recap + comparison;
- raw source/audit metadata.

Semua fitur berguna, tetapi **berguna tidak berarti harus terlihat bersamaan**. Ini sumber utama cognitive overload.

**Keputusan:** ubah menjadi staged workspace dengan tiga mode utama:

1. **TASK** — pilih pekerjaan dan ikuti procedure/preflight.
2. **TUNE** — hanya parameter penting + live effect + Apply/Revert.
3. **ANALYZE** — graph, table, trial comparison, export, raw evidence.

Mode Expert dapat membuka full YAML/raw metadata tanpa memenuhi layar operator biasa.

## 4. Target Information Architecture

### 4.1 Level 1 — Domain tetap sederhana

Top domain dipertahankan karena sudah mudah dipahami:

- **Overview**
- **ESC**
- **Navigation**
- **Perception**

Status global ROS2, motion authority, dan E-stop tetap selalu terlihat di topbar.

### 4.2 Level 2 — True workspace tabs

Setiap domain hanya menampilkan satu workspace utama pada satu waktu.

**Overview:**
- Monitor
- Health
- Authority
- Events
- Replay
- Reports

**ESC:**
- Live
- Control
- Tune
- Configuration
- Diagnostics

**Navigation:**
- Map / Mission
- Sensors
- Localization
- Planner
- Controller
- Safety
- Tune

**Perception:**
- Live
- Calibration
- Detection
- Lane
- Planning
- Safety
- Performance
- Evidence

### 4.3 Level 3 — Progressive disclosure, bukan tab tambahan tanpa akhir

Di dalam workspace gunakan hanya tiga pola:

- **primary surface**: informasi/action yang diperlukan sekarang;
- **details drawer**: telemetry/detail lanjutan;
- **Expert drawer**: raw JSON, YAML path, internal topic, source metadata.

Jangan menambah level tab baru kecuali kontennya benar-benar mutually exclusive.

### 4.4 Aturan satu-fungsi-satu-tempat

Action yang sama tidak boleh muncul di beberapa lokasi aktif sekaligus.

Contoh target:

- parameter umum diedit di TUNE; Full Configuration hanya expert browser;
- recorder START/STOP hanya berada pada TASK/TUNE header yang sticky;
- export trial berada di ANALYZE, bukan juga di setiap graph dan recap kecuali export per-chart;
- perception calibration hanya di `Perception > Calibration`, bukan juga sebagai section panjang di Live;
- safety bypass hanya di Safety/Commissioning context, bukan menjadi kontrol umum di setiap page.

## 5. Redesign Tuning: Basic / Advanced / Expert

Setiap domain tuning harus memiliki complexity mode yang konsisten.

### 5.1 BASIC — default

Ditujukan untuk commissioning normal. Hanya parameter yang benar-benar menjawab tujuan user ditampilkan.

Setiap screen maksimal menampilkan:

- 3–8 parameter utama;
- satu live visual/graph utama;
- satu status target;
- satu action bar: `Apply`, `Revert`, `Validate`;
- warning jika kendaraan harus stationary/restart.

Nama parameter harus human-readable, misalnya `Lane correction strength`, bukan menjadikan YAML path sebagai judul.

### 5.2 ADVANCED

Menambah parameter pendukung, min/max, unit, runtime status, dependencies, dan graph tambahan.

### 5.3 EXPERT

Menampilkan:

- exact YAML key/path;
- source file;
- baseline/current/draft/runtime value;
- raw ROS topic/state bila relevan;
- config fingerprint;
- full parameter browser;
- developer metadata.

Expert harus opt-in dan disimpan di local UI preference, bukan menjadi default setelah refresh pada workstation operator umum.

### 5.4 Tuning dikelompokkan berdasarkan tujuan, bukan nama file YAML

**ESC**
- Steering sensor / center / limits
- Current control / FOC
- Position steering loop
- Velocity loop
- Motor limits / thermal / current
- Validation / step response

**Navigation**
- Vehicle geometry & Ackermann
- Speed calibration
- Local EKF
- Global EKF / GNSS
- Costmap
- Smac Hybrid-A*
- MPPI
- Safety / command authority

**Perception**
- Camera / inference
- Metric calibration
- Object ROI → Nav2
- Lane safety lines
- Lane proportional correction
- Trajectory safety
- Performance / qualification

User memilih “apa yang mau diperbaiki”, lalu UI menentukan parameter yang relevan. Full YAML tetap tersedia untuk engineer.

## 6. Help / Hint System — Wajib Metadata-Driven

Pola utama diambil dari VESC Tool `ConfigParam.longName + description + HelpDialog`, lalu diperluas untuk kebutuhan AGV.

### 6.1 Aturan visual

- **Setiap parameter:** satu tombol kecil `?` di samping label.
- **Setiap box/panel:** satu tombol `?` di header jika fungsi panel belum self-evident.
- **Setiap text-only action button:** wajib mempunyai help metadata; bila action tidak obvious, tampilkan affordance `?`/info di action group.
- **Button yang sudah mempunyai icon yang jelas:** tidak perlu tombol `?` visual tambahan sesuai requirement; tetap wajib `aria-label`/native tooltip untuk accessibility.
- Hover hanya bonus. Klik/tap `?` harus bekerja di touchscreen.
- Jangan menaruh paragraf bantuan panjang secara permanen di setiap card.

### 6.2 Saat hint dibuka

Gunakan satu **Help Drawer** di sisi kanan, bukan modal baru untuk setiap parameter.

Isi minimal:

1. Nama sederhana.
2. “Untuk apa?”
3. Efek jika nilai dinaikkan.
4. Efek jika nilai diturunkan.
5. Unit.
6. Range teknis / recommended range jika valid.
7. Current value, baseline, dan pending value.
8. Apakah apply runtime atau perlu restart/lifecycle reload.
9. Dependency dengan parameter lain.
10. Risiko: `INFO / CAUTION / MOTION / SAFETY-CRITICAL`.

### 6.3 Metadata schema yang disarankan

Tambahkan satu registry UI, misalnya:

```yaml
lane_corridor_correction_gain_m_per_px:
  label: Lane correction strength
  group: Lane Safety
  level: basic
  summary: Besar koreksi steering saat lane melewati safety line.
  unit: m/px
  effect_up: Koreksi menjadi lebih agresif.
  effect_down: Koreksi menjadi lebih lembut.
  risk: motion
  requires_stationary: true
  runtime_apply: true
  related:
    - lane_corridor_touch_margin_px
    - lane_corridor_release_gap_px
```

Registry dapat berada di `src/navigation/web/config/ui_parameter_metadata.yaml` atau di source schema backend. Yang penting: **satu source of truth**, tidak hardcode penjelasan yang sama di banyak template JS.

### 6.4 Help key juga berlaku untuk panel/action

Contoh key:

- `panel.perception.lane_safety`
- `panel.navigation.mppi`
- `action.config.apply_all`
- `action.perception.safety_bypass`
- `action.esc.web_maintenance`

Dengan begitu bahasa, wording, severity, dan dokumentasi dapat diperbarui tanpa mengubah layout.

## 7. Pola dari VESC Tool yang Layak Diterapkan

Audit lokal menemukan pola konkret berikut.

### 7.1 Parameter metadata sebagai sumber UI

`esc/vesc_tool/configparams.cpp` menyediakan long name, description, min, max, step, dan tipe parameter. Widget editor mengambil metadata ini, bukan membuat label/range secara terpisah.

**Terapkan:** renderer parameter ROS Web harus membangun input, slider, enum, help, unit, dan validation dari metadata yang sama.

### 7.2 Help per parameter

`widgets/parameditdouble.cpp`, `parameditint.cpp`, `parameditenum.cpp`, dll memanggil `HelpDialog::showHelp()`, yang mengambil `longName` dan `description` dari parameter.

**Terapkan:** tombol `?` per parameter + satu reusable Help Drawer.

### 7.3 Wizard untuk pekerjaan multi-step

VESC Tool memakai `QWizard` dan setup wizard untuk pekerjaan yang tidak aman bila dilakukan acak.

**Terapkan:** calibration/commissioning AGV menjadi stepper dengan prerequisites, progress, capture state, validation, dan Finish/Apply.

### 7.4 Realtime terpisah dari configuration

VESC Tool tidak memaksa parameter editor, terminal, detection wizard, dan realtime scope terlihat sekaligus.

**Terapkan:** `Live`, `Tune`, `Calibration`, dan `Utilities` menjadi surface berbeda, bukan satu page panjang.

## 8. Pola dari MissionPlanner yang Layak Diterapkan

### 8.1 Friendly configuration vs Full Parameter List

MissionPlanner mempunyai halaman konfigurasi yang task-oriented dan tetap menyediakan `ConfigRawParams` / Full Parameter List.

**Terapkan:**

- default = friendly/task tuning;
- Expert = Full Parameters;
- jangan memaksa user belajar nama YAML untuk commissioning normal.

### 8.2 Metadata range / increment / options

`MavlinkNumericUpDown` mengambil range dan increment dari `ParameterMetaDataRepository`; combo mengambil option dari metadata.

**Terapkan:** input numeric harus memperoleh min/max/step dari schema. Enum harus dropdown. Boolean harus switch. Raw text hanya fallback expert.

### 8.3 Out-of-range warning

MissionPlanner memberi warning sebelum menerima nilai di luar range.

**Terapkan:** ROS Web membedakan:

- hard invalid → tidak dapat di-stage;
- outside recommended → boleh hanya setelah warning;
- safety critical → confirmation + stationary gate;
- impossible dependency → Apply disabled dengan alasan terlihat.

### 8.4 Param compare dan favorites

`ParamCompare` serta favorite/sort pada raw parameter sangat relevan dengan staged config yang sudah mulai ada di ROS Web.

**Terapkan:** tambah compare `Baseline | Runtime | YAML | Draft`, favorite, modified, staged, dan filter level Basic/Advanced/Expert.

### 8.5 Calibration as guided workflow

MissionPlanner calibration pages expose one task at a time and show readiness/progress instead of raw parameter soup.

**Terapkan untuk AGV:**

- IMU/magnetometer calibration;
- steering center/endpoints;
- wheel speed scale;
- camera metric/homography;
- lane safety lines;
- object ROI;
- obstacle distance qualification.

### 8.6 Yang tidak boleh ditiru mentah-mentah

MissionPlanner dan VESC Tool sama-sama dapat menjadi sangat padat untuk engineer lama. ROS Web tidak boleh menyalin:

- terlalu banyak nested tabs;
- singkatan tanpa explanation;
- dialog blocking untuk setiap aksi kecil;
- layout desktop legacy yang sulit di-touch;
- semua parameter ditampilkan hanya karena tersedia.

Prinsipnya adalah mengambil **metadata, wizard, compare, task separation, dan diagnostics**, bukan kepadatan visualnya.

## 9. Matrix Redesign per Domain

### 9.1 Overview

**Pertahankan:** readiness, hardware health, data health, command authority, event timeline.  
**Ubah:** masing-masing menjadi true tab/pane, bukan semua section panjang sekaligus.  
**Gabung:** `Operational Overview` + `Navigation State` menjadi satu compact status strip ketika layar kecil.  
**Expert only:** raw channel diagnostics dan JSON.

### 9.2 ESC

Current ESC sangat lengkap tetapi terlalu panjang.

Target:

- **Live:** dual motor primary telemetry + scope.
- **Control:** LEFT steering / RIGHT velocity command dengan safety state.
- **Tune:** FOC/PID/limits yang relevan dan parameter metadata.
- **Configuration:** MC/App config + read/write/store semantics.
- **Utilities:** connection, firmware, terminal; tampil hanya saat maintenance.
- **Diagnostics:** fault history, decoded variables, compare.

Connection/FW/Terminal jangan berada di antara live graph dan motor telemetry pada workflow normal.

### 9.3 Navigation

Map/Mission tetap primary. Inspector yang sekarang sudah menggunakan true active panes dapat menjadi pola untuk domain lain.

Target side inspector:
- Vehicle
- EKF Local
- EKF Global
- Planner
- MPPI
- Costmap
- Safety
- Command Chain

Raw JSON pindah ke Expert drawer per inspector.

### 9.4 Perception

Current page paling jelas menunjukkan masalah tab-semu karena hampir semua section tetap berada pada page yang sama.

Target:

- **Live:** camera + 4–6 KPI terpenting saja.
- **Calibration:** camera yang sama + interactive lane/ROI overlay + calibration controls.
- **Detection:** object list/bboxes + class/confidence/ROI acceptance.
- **Lane:** lane state, penetration kiri/kanan, proportional correction, mux result.
- **Planning:** object points → path relevant → planning relevant → costmap handoff.
- **Safety:** trajectory gate, emergency/near-field state, bypass commissioning.
- **Performance:** FPS, latency, dropped frame, inference/postprocess.
- **Evidence:** capture/export/qualification.

Camera tidak perlu diduplikasi secara fisik antar pane. Gunakan satu `CameraViewport` component yang mode overlay-nya berubah berdasarkan active workspace.

### 9.5 Perception Calibration khusus

Interactive calibration harus mempunyai mode eksplisit:

1. `VIEW` — overlay visible, pointer disabled.
2. `EDIT LANE` — hanya handle lane aktif.
3. `EDIT OBJECT ROI` — hanya handle ROI aktif.
4. `REVIEW` — tampilkan before/current dan status validation.
5. `APPLIED` — kembali pointer-disabled.

Dengan ini canvas overlay tidak akan menangkap click saat user hanya ingin melihat live camera.

## 10. Tuning State Model yang Harus Terlihat Jelas

Salah satu sumber kebingungan tuning adalah user tidak selalu tahu nilai mana yang sedang dilihat.

Setiap parameter editable harus memiliki empat state eksplisit:

- **BASELINE** — nilai referensi awal/known-good.
- **YAML** — nilai yang tersimpan sebagai source-of-truth.
- **RUNTIME** — nilai yang benar-benar sedang dipakai node saat ini bila dapat dibaca.
- **DRAFT** — nilai yang sedang disiapkan user tetapi belum diterapkan.

UI row ideal:

`Parameter | Runtime | Draft/Input | Unit | Status | ?`

Expanded detail:

`Baseline | YAML path | Apply mode | Restart requirement | Related parameters`

Status yang diperbolehkan:

- `SYNCED`
- `DRAFT`
- `YAML SAVED`
- `RUNTIME APPLIED`
- `RESTART REQUIRED`
- `VERIFYING`
- `ERROR`
- `LOCKED`

Jangan menggunakan label `READY` untuk beberapa arti yang berbeda.

## 11. Apply / Save / Revert Semantics

Gunakan bahasa action yang konsisten di seluruh domain.

- `Stage` = simpan ke Draft saja.
- `Apply` = terapkan Draft ke runtime bila parameter mendukung dynamic update.
- `Save YAML` = commit nilai ke source configuration file secara atomik.
- `Apply + Save` = operasi transaction yang jelas, bukan dua action tersembunyi.
- `Revert Draft` = buang perubahan yang belum diterapkan.
- `Restore Baseline` = membuat Draft dari baseline; belum langsung menulis.
- `Reload Runtime` = lifecycle/restart hanya jika benar-benar dibutuhkan.

Untuk banyak parameter, default harus **batch/staged apply**, seperti workflow parameter engineering MissionPlanner, bukan menulis otomatis setiap kali input berubah.

Auto-write hanya boleh tersedia sebagai Expert preference dan OFF secara default untuk parameter motion/safety.

### 11.1 Transaction safety

Satu batch Apply harus:

1. validate type/range/dependency;
2. cek stationary/motion gate;
3. backup YAML;
4. tulis semua field secara atomik;
5. apply runtime yang didukung;
6. verify runtime readback;
7. rollback bila transaction gagal secara parsial;
8. tampilkan diff dan hasil per parameter.

## 12. CSS Architecture Baru

Target akhir jangan lagi mengandalkan dua stylesheet besar yang saling mengoreksi.

Struktur yang disarankan:

```text
static/css/
  tokens.css
  base.css
  layout.css
  components.css
  pages/
    overview.css
    navigation.css
    perception.css
    esc.css
    tuning.css
    configuration.css
```

Atau tetap build menjadi satu file final, tetapi source harus modular.

### 12.1 Layer contract

1. `tokens`: color, spacing, typography, radius, z-index, breakpoint.
2. `base`: reset, body, form primitive.
3. `layout`: shell, sidebar, topbar, workspace.
4. `component`: panel, tabs, button, field, help, table, graph.
5. `page`: hanya aturan yang benar-benar domain-specific.

Tidak boleh ada page stylesheet yang redefinisi global `.panel`, `.topbar`, `.content`, atau `.button`.

### 12.2 Z-index contract

Definisikan token tetap, misalnya:

- content: `0`
- in-canvas overlay: `10`
- sticky workspace: `20`
- topbar/sidebar: `30`
- dropdown/help popover: `40`
- toast: `50`
- modal/backdrop: `60`

Tidak boleh menambah z-index baru tanpa kategori.

### 12.3 Sticky offset contract

`workspace-tabs` sekarang memiliki fixed `top` yang dapat tidak cocok ketika topbar berubah tinggi pada breakpoint.

Target:

- expose `--topbar-h` dan `--workspace-h`;
- topbar menentukan actual token per breakpoint;
- workspace tabs menggunakan `top: var(--topbar-h)`;
- anchor/scroll margin menggunakan jumlah token yang sama;
- automated test memastikan first content row tidak tertutup sticky bars.

### 12.4 Touch target

Action penting minimum 40–44 px pada touch layout. Desktop engineering density boleh lebih rapat, tetapi click target tidak boleh hanya mengikuti glyph kecil.

## 13. JavaScript Architecture / Component Contract

`app.js` sekarang memegang terlalu banyak domain sekaligus. Refactor bertahap tanpa framework wajib.

Target module:

```text
static/js/
  state.js
  navigation.js
  help.js
  config-store.js
  tuning.js
  widgets/param-field.js
  widgets/help-drawer.js
  widgets/true-tabs.js
  pages/perception.js
  pages/navigation.js
  pages/esc.js
```

### 13.1 TrueTabs component

API minimum:

- `registerWorkspace(domain, panes)`
- `activatePane(domain, paneId)`
- set `hidden`, `aria-hidden`, dan tabIndex dengan benar;
- restore last pane per domain;
- deep-link optional via URL hash;
- tidak memakai `scrollIntoView` sebagai mekanisme navigasi primer.

### 13.2 Shared Help component

Semua `data-help-key` menggunakan satu event delegation. Jangan membuat ratusan handler per button.

## 14. Backend / API yang Perlu Dirapikan untuk UX Tuning

Pertahankan atomic YAML write yang sudah ada, tetapi expose semantics yang lebih jelas.

Endpoint target konseptual:

- `GET /api/config/schema` — metadata field, range, unit, options, help, apply mode.
- `GET /api/config/state` — baseline/YAML/runtime consistency.
- `POST /api/config/validate` — validasi draft batch tanpa menulis.
- `POST /api/config/apply` — transaction batch.
- `POST /api/config/revert` — rollback ke snapshot/baseline yang dipilih.

Tidak wajib mengganti endpoint lama sekaligus. Tambahkan adapter lebih dulu agar UI baru bisa migrasi bertahap.

### 14.1 Runtime capability metadata

Setiap parameter harus mengatakan salah satu:

- `dynamic`
- `lifecycle_reload`
- `node_restart`
- `startup_only`
- `read_only`

UI tidak boleh menebak apply mode dari nama file.

### 14.2 Dependency metadata

Contoh dependency yang harus dapat diekspresikan:

- field hanya relevan bila feature enabled;
- field B harus lebih besar daripada field A;
- lane control tidak boleh enable sebelum calibration validated;
- motion test tidak dapat start bila E-stop/telemetry/preflight belum memenuhi gate.

## 15. Automated Overlay / Duplicate UX QA

Tidak cukup mengandalkan inspeksi mata. Tambahkan browser QA khusus layout.

### 15.1 Resolusi wajib

- 1920×1080
- 1600×900
- 1366×768
- 1280×720
- 1024×768
- 820×1180
- 768×1024
- 430×932
- 390×844

### 15.2 Overlap detector

Playwright membaca `getBoundingClientRect()` semua elemen interactive/major panels lalu melaporkan intersection yang tidak berada dalam allow-list.

Allow-list hanya untuk:

- modal/backdrop;
- toast;
- map layer panel di map viewport;
- perception calibration canvas di camera viewport;
- context visual pane yang active.

Test harus gagal bila:

- button/input saling bertumpuk;
- sticky header menutup heading/form;
- panel keluar viewport horizontal;
- hidden pane masih menerima pointer/focus;
- dua context pane visible sekaligus;
- placeholder menutup media aktif.

### 15.3 Screenshot regression

Ambil screenshot per domain + per mode Basic/Advanced/Expert dan simpan artifact QA, bukan commit screenshot setiap run ke source tree.

## 16. Implementation Phases

### Phase 0 — Baseline & inventory (P0)

- Jalankan ROS Web runtime read-only.
- Capture screenshot semua domain/resolusi.
- Simpan DOM panel inventory.
- Tambah initial overlap detector.
- Catat action/parameter yang muncul di lebih dari satu active surface.

**Exit:** baseline reproducible tersedia sebelum redesign.

### Phase 1 — True workspace navigation (P0)

- Ganti semua primary `anchor:*` tabs menjadi pane state.
- Pertahankan URL/deep-link compatibility bila dibutuhkan.
- `Perception`, `ESC`, `Overview` menjadi target pertama.
- Pastikan inactive pane `hidden` dan tidak focusable.

**Exit:** satu workspace tab = satu content workspace.

### Phase 2 — CSS consolidation (P0)

- Buat token authoritative.
- Freeze penambahan override baru.
- Pindahkan style final dari dua stylesheet ke layer modular.
- Hapus selector obsolete setelah screenshot parity.
- Definisikan z-index dan sticky offsets.

**Exit:** satu selector global mempunyai satu source styling utama.

### Phase 3 — Help metadata + Help Drawer (P1)

- Tambah schema parameter/panel/action.
- Buat reusable `HelpButton` dan `HelpDrawer`.
- Migrate parameter Basic lebih dulu.
- Tambah `data-help-key` untuk box dan text-only action.
- Tambah aria-label/title untuk icon-only controls.

**Exit:** tidak ada parameter Basic tanpa explanation yang dapat dibuka dengan satu click/tap.

### Phase 4 — Tuning TASK / TUNE / ANALYZE (P1)

- Pisahkan procedure/preflight dari parameter editor.
- Pisahkan graph/trial/export ke Analyze.
- Tambah Basic/Advanced/Expert switch.
- Default auto-write YAML menjadi staged transaction untuk motion/safety parameter.
- Buat sticky pending-change bar yang compact.

**Exit:** user dapat menyelesaikan satu tuning task tanpa scroll melewati panel yang tidak diperlukan.

### Phase 5 — Guided calibration (P1)

- Steering endpoints/center wizard.
- Speed scale wizard.
- Camera metric/homography wizard.
- Lane + Object ROI direct calibration.
- Obstacle distance qualification.
- IMU/magnetometer wizard.

**Exit:** tiap calibration mempunyai prerequisite, progress, validation, save/apply, dan recovery yang jelas.

### Phase 6 — Config transaction + compare (P1)

- Tambah batch validate/apply/readback.
- Tampilkan Baseline/YAML/Runtime/Draft.
- Tambah compare dan diff sebelum apply.
- Tambah rollback hasil transaction.
- Pertahankan favorite/modified/staged filter.

**Exit:** tidak ada kondisi user mengira nilai sudah runtime padahal baru tersimpan di YAML.

### Phase 7 — Density, responsive, accessibility (P2)

- Touch target audit.
- Keyboard tab/focus audit.
- Contrast/status semantics.
- Mobile/tablet layout.
- Kurangi raw JSON dari default surface.
- Hilangkan hidden legacy DOM yang tidak lagi dipakai.

### Phase 8 — Regression & cleanup (P0 sebelum merge final)

- Browser QA seluruh resolusi.
- Screenshot comparison.
- Zero unexpected overlap.
- Zero horizontal document overflow.
- Zero duplicate active action.
- Test read-only mode dan replay mode.
- Test active runtime mode tanpa mengirim motion command otomatis.

## 17. Backlog Konkret: Keep / Merge / Move / Remove

| Area sekarang | Keputusan | Target |
|---|---|---|
| Workspace tabs berbasis `anchor:` | **REMOVE sebagai navigation behavior** | True pane activation; anchor hanya untuk deep-link/docs |
| `legacy-domain-switch` hidden | **REMOVE setelah migrasi** | Satu domain/navigation source saja |
| Perception Camera + seluruh section di bawahnya | **SPLIT** | Live / Calibration / Detection / Lane / Planning / Safety / Performance / Evidence |
| Perception Lane + Planning cards di kanan camera | **KEEP tetapi contextual** | Live summary compact; detail penuh di masing-masing pane |
| Perception calibration canvas | **KEEP** | Hanya pointer-active pada EDIT mode |
| Perception Safety Bypass di Live camera | **MOVE** | Safety / Commissioning pane |
| ESC Connection/FW/Terminal di workbench utama | **MOVE** | Utilities / Maintenance pane |
| ESC decoded telemetry detail | **MOVE/COLLAPSE** | Expert drawer / Diagnostics |
| ESC graphs + telemetry | **KEEP** | Live pane, satu primary scope per motor |
| Tuning roadmap | **KEEP, COMPACT** | Task header / progress strip |
| Phase tabs + family tabs + chapter browser | **MERGE** | Satu task navigator + search/filter |
| Trial Guide + Preflight | **MERGE** | TASK pane: procedure + readiness |
| Run Control | **KEEP** | Sticky task/run toolbar saat recording |
| Parameter editor | **KEEP/REDESIGN** | TUNE pane, Basic/Advanced/Expert |
| Context visual | **KEEP** | TUNE pane, satu active visual |
| Graph + report table + trial recap | **MOVE** | ANALYZE pane |
| Raw catalog/source metadata | **MOVE** | Expert drawer |
| Full YAML Configuration | **KEEP** | Expert engineering browser, bukan tuning default |
| Inline help paragraphs panjang | **REDUCE** | Ringkas 1-line hint + Help Drawer |

## 18. Prioritas Help Metadata

Urutan rollout agar nilai praktis muncul cepat:

**P0 — motion/safety:** E-stop-related state, ESC maintenance/control, Ackermann, MPPI command limits, lane correction, safety bypass, object ROI, trajectory safety.

**P1 — calibration:** steering endpoints, speed scale, EKF noise/rejection, GNSS gates, camera metric/homography, lane thresholds, obstacle qualification.

**P2 — diagnostics/report:** graph options, export controls, raw telemetry fields, evidence metadata.

Setiap metadata baru harus mempunyai review sederhana:

- label dapat dipahami tanpa nama source variable;
- unit benar;
- effect-up/effect-down tidak misleading;
- range berasal dari constraint nyata, bukan angka UI arbitrer;
- dependency dan restart semantics benar;
- risk classification sesuai dampak kendaraan.

## 19. Definition of Done UX

Redesign dianggap selesai hanya jika:

- satu secondary tab hanya menampilkan workspace yang dipilih;
- tidak ada unexpected overlap pada seluruh viewport QA;
- tidak ada document-level horizontal overflow;
- tidak ada action motion/safety yang muncul dua kali pada active context;
- semua parameter Basic/Advanced mempunyai help yang dapat dibuka dengan tap;
- text-only action yang tidak self-explanatory mempunyai help metadata;
- icon-only action mempunyai `aria-label`/tooltip yang jelas;
- user selalu dapat membedakan Baseline, YAML, Runtime, dan Draft;
- perubahan safety/motion tidak auto-write hanya karena input berubah;
- Apply menampilkan validation/readback result;
- Expert/raw UI tidak mengganggu default workflow;
- replay/read-only tetap memblokir write dan motion command;
- browser QA berjalan tanpa console error dan screenshot regression yang tidak dijelaskan.

## 20. Urutan File Implementasi yang Disarankan

Urutan ini meminimalkan risiko merusak runtime yang sedang dikembangkan paralel.

1. `scripts/qa_ros_web_playwright.js` / layout QA baru — buat baseline dan detector dulu.
2. `static/app.js` — tambah true workspace pane state tanpa mengubah backend.
3. `static/index.html` — beri wrapper/pane semantics dan pindahkan section, tanpa menghapus ID telemetry yang masih dipakai renderer.
4. CSS — konsolidasi setelah struktur pane stabil; jangan mengejar visual dengan override baru.
5. Help metadata registry + renderer Help Drawer.
6. Tuning renderer — Basic/Advanced/Expert + TASK/TUNE/ANALYZE.
7. Configuration transaction/readback UI.
8. Backend schema/validate/apply adapter bila metadata/runtime semantics belum tersedia.
9. Hapus legacy DOM/CSS/handler setelah coverage QA membuktikan tidak dipakai.

Saat refactor, ID telemetry dan endpoint yang sudah digunakan backend harus dipertahankan sampai migration layer selesai. Tujuannya mengubah UX tanpa memutus data contract ROS yang sudah berjalan.

## 21. Non-Goals dan Safety Guardrail

Redesign ini **tidak** bertujuan:

- menyembunyikan capability engineering; capability dipindah ke tempat yang tepat;
- mengubah algoritma Nav2/perception/ESC hanya demi tampilan;
- membuat UI otomatis memilih gain “terbaik” tanpa objective metric yang eksplisit;
- mengaktifkan calibration/safety flag hanya karena wizard selesai secara visual;
- mengirim motion command saat page dibuka, tab diganti, config dibaca, atau QA dijalankan.

Semua wizard yang dapat memengaruhi gerak harus tetap memakai existing command authority, stationary gate, E-stop, watchdog, finite-command check, dan readback/validation yang sesuai.

## 22. Contoh User Journey Target

### 22.1 Tune Lane Safety

1. Buka `Perception > Calibration`.
2. Camera viewport tampil satu kali.
3. Klik `Edit Lane` lalu drag garis kiri/kanan.
4. Help `?` menjelaskan touch margin, release gap, dan Kp.
5. Buka `Tune` untuk mengubah strength/threshold; live pane menunjukkan penetration dan correction.
6. Draft berubah tetapi kendaraan belum menerima perubahan otomatis.
7. Klik `Validate` → dependency/range/stationary gate diperiksa.
8. Klik `Apply + Save` → YAML transaction + runtime apply + readback.
9. Status menjadi `RUNTIME APPLIED` atau `RESTART REQUIRED` secara eksplisit.
10. Buka `Analyze` bila ingin merekam trial/graph/compare.

### 22.2 Tune MPPI

1. Buka `Navigation > Tune` dan pilih goal `Controller / MPPI`.
2. Basic hanya menampilkan parameter yang paling relevan untuk behavior target.
3. Hover/tap `?` memberi efek naik/turun dan dependency.
4. Context visual tetap map/path, bukan raw JSON.
5. Advanced membuka weights/constraints tambahan.
6. Analyze memperlihatkan tracking error, velocity, steering, clearance, dan compare trial.

### 22.3 ESC Commissioning

1. `ESC > Live` memastikan telemetry sehat.
2. `ESC > Control` hanya menampilkan command yang relevan dan authority state.
3. `ESC > Tune` memakai group Steering/FOC/Velocity/Limit.
4. `ESC > Utilities` baru dibuka saat perlu maintenance/terminal/firmware.
5. Expert dapat membuka decoded variable dan full config tanpa memenuhi layar operator.

## 23. Kesimpulan Audit

Masalah utama ROS Web saat ini bukan duplicate HTML ID. Masalah utamanya adalah **information architecture dan accumulated styling**: secondary tab masih scroll-to-anchor, banyak feature berguna dirender bersamaan, dan dua stylesheet besar mempunyai ratusan selector yang saling override.

Arah redesign yang direkomendasikan adalah:

**True Workspaces + Task-oriented Tuning + Metadata-driven Help + Staged Parameter Transactions + Expert Progressive Disclosure + Automated Layout QA.**

Dengan pola ini ROS Web tetap sekuat VESC Tool/MissionPlanner untuk engineer, tetapi commissioning harian lebih tenang, jelas, dan tidak membuat user harus memahami seluruh internal ROS/YAML sekaligus.

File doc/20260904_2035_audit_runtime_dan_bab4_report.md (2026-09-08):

# Audit Runtime ROS dan Integrasi Laporan BAB IV — 2026-09-04

## Ruang lingkup
Audit workspace `$AGV_ROOT` mencakup paket `esc`, `navigation`, `perception`, dan `stmf4`, konfigurasi YAML, launch ROS 2, self-check, lifecycle runtime, serta integrasi ROS Web.

## Temuan dan perbaikan
- Ditemukan instance stack ROS lama berjalan bersamaan dan memicu konflik lock HMI/port web; proses duplikat dibersihkan sebelum pengujian ulang.
- Lifecycle `semantic_obstacle_node.py` telah dibuat aman terhadap shutdown ROS agar tidak publish setelah context invalid dan tidak melakukan shutdown ganda.
- `trajectory_safety.command_collision_horizon_m` diselaraskan menjadi 2.0 m sehingga lebih kecil daripada `slow_path_distance_m` 2.2 m dan kontrak safety kembali konsisten.
- Self-check katalog Navigasi diperbarui mengikuti katalog aktual minimal 84 leaf.
- Kontrak Mini-PC diperbarui mengikuti arsitektur lazy YOLOPv2: default OFF, inference OFF, dan CPU thread dibatasi 2.
- Sidebar Navigasi memperoleh kelompok Laporan BAB IV 4.1.1–4.4.3 yang memakai source tuning existing, recorder 1 Hz, YAML tuning, CSV/Excel, grafik, dan rekap data.
- Export Excel menambahkan kolom parameter tuning terpisah dengan style ungu agar nilai tuning mudah dibedakan dari measurement.
- Inferensi kolom laporan diperluas untuk planner success, path endpoint error, GNSS age/rate, dan residual IMU.

## Validasi sementara
- Syntax Python: PASS.
- XML package: PASS.
- YAML parse: PASS.
- Shell syntax: PASS.
- Launch Python syntax/import: PASS.
- ROS package resolution: PASS untuk `esc`, `navigation`, `perception`, `stmf4`.
- Regression self-check sebelum perubahan web terbaru: 41 PASS / 0 FAIL.

## Catatan verifikasi lanjutan
Setelah commit/sinkronisasi, wajib dijalankan kembali full self-check, build dengan maksimum sekitar 70% CPU/RAM, `colcon test`, lalu runtime `autonomous.launch.py mode:=web` dan pemeriksaan node/topic/log/resource sebelum dinyatakan siap uji penuh.

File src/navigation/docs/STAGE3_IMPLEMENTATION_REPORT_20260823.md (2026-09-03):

# Stage 3 Implementation Report — Nav2 Ackermann Outdoor + Production Safety

**Date:** 2026-08-23  
**Baseline:** `src_mobil_stage2_gnss_imu_odometry_fusion_fixed_20260823.zip`  
**Scope:** final Nav2 Ackermann outdoor commissioning layer after Stage 1 physical geometry/odometry and Stage 2 GNSS–IMU fusion.

## 1. Goals

Stage 3 makes the autonomous command chain physically feasible for Ackermann motion, aligns Smac/MPPI/smoother/safety authority, adds a low-speed commissioning mode, and makes production autonomy fail-closed until persistent evidence exists for MPPI, trajectory safety, Collision Monitor, and fault injection.

The invariant enforced at the command boundaries is:

`|omega| <= |v| / Rmin`

where `Rmin` comes from the vehicle steering/circle-calibration authority.

## 2. Major fixes

### 2.1 Dynamic Ackermann curvature clamp in NavigationCore
Previously `NavigationCore` clamped yaw rate only against a fixed maximum. At low linear speed, a fixed yaw command can imply a turning radius smaller than the physical vehicle radius. The Stage 3 implementation computes the yaw ceiling dynamically from current command speed and `minimum_turning_radius_m` before publishing downstream.

### 2.2 Dynamic curvature clamp after TrajectorySafety slowdown
TrajectorySafety could reduce `linear.x` for obstacle/lane risk without proportionally reducing `angular.z`. That changes curvature and can make a command less physically feasible while attempting to slow down. The final output is now re-clamped against `|v|/Rmin` after all speed/risk scaling.

### 2.3 One kinematic authority across calibration and tuning
Steering/circle recalibration now propagates minimum turning radius to:
- `vehicle.yaml`
- Smac Hybrid-A* `minimum_turning_radius`
- MPPI `AckermannConstraints.min_turning_r`
- `NavigationCore.minimum_turning_radius_m`
- `TrajectorySafety.minimum_turning_radius_m`

The GUI MPPI A/B/C profile apply path also updates `vx_max`, `wz_max`, velocity-smoother limits, and trajectory-safety yaw authority together so a speed profile cannot silently violate Ackermann geometry.

### 2.4 Stage 3 production gate
`NavigationCore` now supports:
- `require_stage3_production_certification`
- `stage3_production_certified`
- `stage3_commissioning_mode`
- `stage3_commissioning_speed_cap_mps`

Production baseline is fail-closed. Stage 3 field testing requires an explicit launch argument:

`stage3_commissioning_mode:=true`

The default commissioning autonomous speed cap is `0.18 m/s`. Stage 1/2 prerequisites remain required; commissioning mode is not a bypass for physical/localization validity.

### 2.5 Persistent Stage 3 evidence
New `stage3_navigation.yaml` stores commissioning thresholds and certification state for:
- MPPI profile
- optional CLOSED_LOOP velocity smoother
- trajectory safety
- Collision Monitor
- fault injection
- final production autonomy sign-off

Evidence written by `stage3_certify.py` stores the source file path and SHA-256. `stage3_commissioning_check.py` re-hashes certified evidence. Missing or changed evidence returns a configuration error.

### 2.6 Camera / Collision Monitor runtime gate included in final sign-off
Final production certification requires both the persistent camera metric certificate and the actual `NavigationCore` runtime safety authority (`require_camera_metric_calibration`, `camera_metric_calibration_validated`, `collision_monitor_enabled`). This prevents a stale GUI certificate from being treated as sufficient if the runtime safety gate is disabled.

### 2.7 GUI/report snapshot coverage
`stage3_navigation.yaml` is added to the GUI workspace file map so configuration snapshots and reports include Stage 3 state alongside Nav2/vehicle/localization configuration.

## 3. New files

- `src/navigation/config/stage3_navigation.yaml`
- `src/navigation/docs/STAGE3_NAV2_ACKERMANN_OUTDOOR_SAFETY.md`
- `src/navigation/test/stage3_nav2_safety_self_check.py`
- `src/navigation/tools/stage3_nav2_csv_analyzer.py`
- `src/navigation/tools/stage3_commissioning_check.py`
- `src/navigation/tools/stage3_certify.py`

## 4. Modified files

- `src/navigation/CMakeLists.txt`
- `src/navigation/config/navigation_core.yaml`
- `src/navigation/config/trajectory_safety.yaml`
- `src/navigation/gui/agv_gui.cpp`
- `src/navigation/launch/autonomous.launch.py`
- `src/navigation/src/navigation_core.cpp`
- `src/navigation/src/trajectory_safety_supervisor.cpp`

## 5. Stage 3 commissioning sequence

1. Finish Stage 1 physical steering, LUT/hysteresis, drive scale, and circle geometry.
2. Finish Stage 2 stationary IMU and GNSS velocity certification; COG is required only if COG fusion is enabled.
3. Certify camera metric calibration and enable the production Collision Monitor runtime gate.
4. Run Stage 3 preflight. `WAIT` is expected before field evidence; `CONFIG ERROR` must be fixed before motion.
5. Start autonomy explicitly in Stage 3 commissioning mode (0.18 m/s default cap).
6. Run MPPI profile A, then B, and C only if needed. Record the same route/test set for comparable evidence.
7. Analyze the tuning CSV with `stage3_nav2_csv_analyzer.py`; certify the selected profile only if thresholds pass.
8. Record and mark trajectory-safety and Collision Monitor evidence.
9. Perform fault injection: GNSS disconnect/reconnect, IMU dropout, ESC/Prolific disconnect, camera dropout/stale perception, Nav2 cancel, and E-STOP.
10. Run `stage3_certify.py finalize`. It succeeds only when persistent prerequisites and evidence are valid and evidence hashes still match.
11. Restart normal autonomous launch without commissioning mode and run `stage3_commissioning_check.py --require-ready`.

## 6. Baseline state distributed in the ZIP

The final ZIP deliberately retains all real-world calibration/certification flags as `false`. This is not an implementation failure: hardware measurements cannot be fabricated. The expected pre-field state is `CONFIG SAFE, FIELD COMMISSIONING BELUM LENGKAP`.

## 7. Regression result

- Python syntax: **42 PASS**
- YAML parse: **22 PASS**
- XML/Xacro/URDF parse: **16 PASS**
- Navigation Python self-checks: **20/20 PASS**
- Standalone C++ math/safety checks: **6/6 PASS** using `-std=c++17 -Wall -Wextra -Wpedantic -Werror`
- Simulated valid evidence path reaches **STAGE-3 PRODUCTION READY**
- Tampered evidence is detected and preflight returns **CONFIG ERROR**
- Active legacy FTDI selector: absent
- Fixed `/dev/ttyUSB<N>` active device selection: absent

The audit container does not contain ROS 2/colcon/Qt5, therefore the target Jetson still must run a clean `colcon build` and `colcon test` before hardware testing.

## 8. Key field commands

```bash
cd ~/Sistem-Otomasi-Car/Car-MiniPC/ros
source /opt/ros/humble/setup.bash

ros2 run navigation stage3_commissioning_check.py --workspace "$PWD"

ros2 launch navigation autonomous.launch.py stage3_commissioning_mode:=true

ros2 run navigation stage3_nav2_csv_analyzer.py /path/to/mppi_tuning.csv

ros2 run navigation stage3_certify.py --workspace "$PWD" \
  mppi --csv /path/to/mppi_tuning.csv --profile B

ros2 run navigation stage3_certify.py --workspace "$PWD" \
  mark trajectory_safety --evidence /path/to/trajectory_safety_evidence.txt

ros2 run navigation stage3_certify.py --workspace "$PWD" \
  mark collision_monitor --evidence /path/to/collision_monitor_evidence.txt

ros2 run navigation stage3_certify.py --workspace "$PWD" \
  mark fault_injection --evidence /path/to/fault_injection_evidence.txt

ros2 run navigation stage3_certify.py --workspace "$PWD" finalize
ros2 run navigation stage3_commissioning_check.py --workspace "$PWD" --require-ready
```

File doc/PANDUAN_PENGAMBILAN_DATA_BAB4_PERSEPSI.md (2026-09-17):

# Panduan Pengambilan Data BAB IV dan Kalibrasi GUI Persepsi

Acuan implementasi aktual: `/home/sirobo/agv/src/navigation/web/static/perception_bab4.js`, `perception_calibration.js`, `tuning_evidence.js`, serta konfigurasi `/home/sirobo/agv/src/perception/config/astra_yolop_gpu.yaml`.
Acuan laporan: Subbab 3.12, BAB IV 4.1–4.4, dan Lampiran 2 pada laporan Tugas Akhir Davi.

> Prinsip utama: data FINAL laporan harus berasal dari pengujian aktual. Jangan mempertahankan angka DATA ESTIMASI sebagai hasil akhir.

## 1. Urutan kerja yang disarankan

1. Jalankan sistem dan pastikan kamera Astra serta YOLOPv2 CPU aktif.
2. Selesaikan kalibrasi persepsi yang diperlukan terlebih dahulu.
3. Simpan snapshot konfigurasi efektif sebelum pengambilan data final.
4. Buka **PERSEPSI → Tune** untuk masuk ke mode **FINAL BAB IV 4.1–4.4**.
5. Ikuti urutan **Pilih Tahap → Cek Source → START/CAPTURE → STOP + SAVE → XLSX/PNG**.
6. Jangan pindah subbab/experiment ketika recorder masih aktif; lakukan **STOP + SAVE** terlebih dahulu.
7. Simpan CSV/XLSX/PNG/manifest untuk setiap run sebagai evidence sidang.

## 2. Preflight sebelum kalibrasi atau pengambilan data

Pastikan pada GUI:
- Camera = ONLINE dan camera health = HEALTHY.
- YOLOPv2 CPU inference = ON.
- Backend yang dipakai untuk data laporan adalah CPU sesuai rancangan laporan final.
- `/perception/raw_detections` fresh untuk 4.2 dan 4.4.
- `/perception/lane_safety_state` fresh untuk 4.3.
- `/perception/performance` fresh untuk pengujian performa.
- Tombol START menampilkan kondisi READY, bukan BLOCKED.

### Verifikasi terminal yang berguna

```bash
source /opt/ros/humble/setup.bash
source /home/sirobo/agv/install/setup.bash
ros2 topic hz /perception/raw_detections
ros2 topic hz /perception/lane_safety_state
ros2 topic hz /perception/performance
ros2 param dump /perception
```

Simpan hasil `ros2 param dump /perception` bersama run final. Catat juga model, backend, resolusi kamera, FPS request, `cpu_inference_fps`, `cpu_threads`, dan parameter threshold yang tampil di GUI.

# BAGIAN A — KALIBRASI GUI PERSEPSI

## 3. Kalibrasi Lane Safety / Object ROI

Buka **PERSEPSI → Calibration → Lane Safety / ROI**.

GUI membaca nilai awal dari YAML authoritative melalui `/api/config`; jika muncul **WAIT CONFIG**, jangan melakukan kalibrasi sampai konfigurasi berhasil dibaca. Nilai fallback tidak dipakai sebagai candidate.

Untuk Lane Safety tersedia empat handle:
- **LT** = kiri atas
- **LB** = kiri bawah
- **RT** = kanan atas
- **RB** = kanan bawah

Handle dapat di-drag pada citra. Keyboard `1–4` memilih handle; tombol panah melakukan fine adjustment, sedangkan `Shift + panah` melakukan langkah lebih besar.

Aturan geometri yang diperiksa GUI:
- Y atas harus berada 0–0,90.
- Y bawah maksimal 0,995 dan minimal 0,05 lebih rendah dari Y atas.
- Garis kiri dan kanan tidak boleh saling silang.
- `lane_corridor_correction_gain_m_per_px` harus berada 0–0,05.
- ROI terdiri dari 4 titik normalized 0–1 dan tidak boleh degenerate/terlalu kecil.

Workflow penyimpanan:
1. Atur titik sampai overlay sesuai geometri kendaraan dan lane aktual.
2. Pastikan status bukan `INVALID` atau `YAML CHANGED`.
3. Klik **Stage + Review Calibration**.
4. Buka/review diff konfigurasi yang di-stage.
5. Lakukan **Apply** hanya setelah diff benar dan validasi PASS.
6. Reload konfigurasi lalu pastikan overlay tetap sama dengan nilai YAML aktif.

Jangan menganggap tombol Stage sebagai Apply. Implementasi saat ini sengaja memisahkan proposal, validation, dan commit ke YAML.

## 4. Kalibrasi jarak obstacle — 40 kombinasi

Buka **PERSEPSI → Calibration → Obstacle Calibration**. Wizard menggunakan `/perception/semantic_detections` untuk kalibrasi metrik; data ini berbeda dari `raw_detections` yang dipakai untuk statistik utama BAB IV 4.2.

Total kombinasi wajib wizard:
- 2 objek: **Human** dan **Motorcycle**.
- 4 orientasi: **Depan, Belakang, Samping Kiri, Samping Kanan**.
- 5 jarak ground-truth: **1, 2, 3, 4, 5 m**.
- Total = **40 capture**.

Syarat agar tombol capture aktif:
- kamera terhubung dan sehat;
- stream `semantic_detections` fresh;
- kelas yang dipilih terdeteksi dengan confidence memenuhi gate;
- objek cukup berada di tengah citra;
- titik bawah bbox tersedia;
- untuk jarak 3–5 m, bbox tidak boleh terpotong di bawah dan `raw_forward_m` harus valid.

Prosedur setiap kombinasi:
1. Ukur jarak fisik dari referensi depan kamera ke titik kontak objek pada tanah.
2. Pilih Object, Orientation, dan Distance pada wizard.
3. Posisikan satu objek utama dan tunggu bbox stabil serta status **CAPTURE READY**.
4. Klik **OK / Capture** sekali.
5. Baris yang berhasil akan menjadi **LOCK**; lanjutkan ke kombinasi berikutnya.
6. Jika capture salah, gunakan **RESET** pada baris itu saja lalu ulangi.

Setelah 40/40 lengkap, GUI membentuk fit terpisah Human dan Motorcycle. Fit metrik memakai sampel 3–5 m yang tidak clipped dan mempunyai `raw_forward_m` valid.

Urutan akhir kalibrasi obstacle:
1. Periksa grafik raw vs calibrated serta MAE yang tampil.
2. Klik **SAVE CALIBRATION**; ini membuat proposal dan menjalankan validation.
3. Setelah status **SAVED + VALIDATED**, klik **APPLY TO YAML**.
4. Ekspor **CSV Calibration** dan **PNG Graph** sebagai evidence.
5. Restart/reload runtime bila diperlukan oleh workflow configuration, lalu verifikasi koefisien aktif.

Catatan: kalibrasi obstacle metrik tidak boleh digunakan untuk “memperbaiki” jumlah berhasil/gagal pada pengujian raw YOLOPv2 4.2. Keduanya adalah jalur evaluasi berbeda.

# BAGIAN B — PENGAMBILAN DATA FINAL BAB IV

## 5. BAB IV 4.1 — Implementasi Sistem Persepsi Visual

Buka **PERSEPSI → Tune → 4.1 Implementasi**. Tahap ini merupakan audit implementasi, bukan pengujian massal.

Evidence yang harus disimpan:
- kamera Astra tampil aktual;
- YOLOPv2 inference aktif;
- backend tercatat CPU;
- raw detection, Lane Safety, dan performance telemetry tersedia;
- parameter/configuration efektif tersimpan;
- screenshot GUI yang menunjukkan kondisi runtime aktual, bukan screenshot saat YOLO OFF.

Ambil snapshot `ros2 param dump /perception` pada sesi final. Jika memungkinkan, simpan juga identitas commit/source dan model yang dipakai agar data 4.2–4.4 dapat direproduksi.

## 6. BAB IV 4.2 — Object Detection YOLOPv2

Target utama: **200 percobaan** = 2 target × 5 jarak × 20 ulangan.

Konfigurasi protokol:
- Target fisik: Human dan Motorcycle.
- Jarak fisik: 1, 2, 3, 4, 5 m.
- Ulangan: 20 untuk setiap kombinasi target-jarak.
- Beri jeda sekurang-kurangnya ±2 s antarpengamatan agar frame tidak hampir identik.
- Gunakan satu target utama pada frame evaluasi.

Definisi capture:
- **BERHASIL** bila bbox kandidat setelah NMS melingkupi sasaran fisik utama secara spasial.
- Bila ada beberapa bbox pada sasaran, pilih kandidat dengan confidence tertinggi yang memenuhi kriteria spasial.
- Bbox pada latar/objek lain tidak boleh menggantikan kegagalan sasaran.
- Kondisi meragukan dicatat sebagai **GAGAL** dan beri alasan pada Catatan Visual.
- Confidence hanya dicatat untuk kandidat BERHASIL; trial gagal jangan diisi confidence = 0.

Langkah GUI:
1. Pilih card **4.2 Object Detection**.
2. Pastikan preflight menunjukkan YOLOPv2 CPU inference dan raw detection stream siap.
3. Klik **START** sekali untuk membuka sesi evidence.
4. Pilih Target Fisik, Jarak GT, dan Ulangan.
5. Pada frame yang sudah dijadwalkan, pilih kandidat bbox yang sesuai sasaran.
6. Klik **Capture BERHASIL** atau **Capture GAGAL**.
7. GUI akan maju otomatis ke ulangan/jarak/target berikutnya; pantau progress hingga 200/200.
8. Gunakan **Undo** bila salah klik, bukan mengedit hasil diam-diam setelah sesi selesai.

Jarak ground-truth harus diukur fisik dari referensi depan kamera ke titik kontak target pada tanah. Jangan memakai estimasi homografi sebagai GT pengujian 4.2.

### Uji negatif 4.2.5

Setelah/di dalam sesi 4.2, ambil **30 frame negatif**:
- 10 frame indoor tanpa manusia/motor;
- 10 frame jalur relatif kosong;
- 10 frame latar statis dengan objek non-target.

Setiap kandidat yang muncul pada frame negatif dicatat sebagai kandidat palsu terhadap protokol target manusia/motor. Simpan catatan dan, bila perlu, screenshot/frame bukti untuk kasus false candidate.

Setelah 200 trial + uji negatif selesai, klik **STOP + SAVE**. Pastikan tabel rekap menghasilkan Detection Rate, Error, dan confidence rata-rata per target/jarak. Gunakan grafik otomatis **Detection Rate vs jarak** dan **Confidence vs jarak**, lalu ekspor PNG.

Penting: statistik 4.2 memakai `/perception/raw_detections`. Kandidat 5 m tetap boleh dihitung sebagai keberhasilan raw detection walaupun jalur metric/obstacle safety dapat menolaknya karena batas jarak, ROI, atau drivable-contact.

## 7. BAB IV 4.3 — Lane Safety

Target utama: **80 percobaan** = 4 kondisi × 20 ulangan.

Empat kondisi acuan:
- **Abu-abu**: tidak ada bukti mask yang memadai → UNKNOWN / NO_MASK_EVIDENCE.
- **Hijau**: jalur clear → kiri dan kanan GREEN, recommendation CLEAR.
- **Kuning**: lane mendekati boundary → sisi uji YELLOW, sisi lain GREEN, recommendation WARNING.
- **Merah**: lane menyentuh/masuk koridor → sisi uji RED; intrusi kiri mengharapkan RECENTER_RIGHT dan intrusi kanan RECENTER_LEFT.

Untuk kondisi Kuning dan Merah, implementasi GUI membagi sisi otomatis: ulangan **1–10 kiri**, ulangan **11–20 kanan**.

Langkah GUI:
1. Pilih card **4.3 Lane Safety** dan pastikan stream lane fresh.
2. Klik **START**.
3. Pilih kondisi acuan; untuk Kuning/Merah sisi mengikuti protokol otomatis.
4. Bentuk kondisi fisik/mask, lalu tunggu keadaan stabil.
5. Pastikan ground truth ditentukan dari penempatan aktual dan inspeksi mask, bukan sekadar menyalin warna output GUI.
6. Klik **Capture + Auto Compare** satu kali untuk frame evaluasi.
7. GUI mencatat gap kiri/kanan, warna/status kedua sisi, latch, recommendation, expected, dan hasil BENAR/SALAH.
8. Lanjutkan sampai progress 80/80 lalu **STOP + SAVE**.

### Verifikasi histeresis 4.3.5

Gunakan panel **Verifikasi Histeresis**. Urutan acuan GUI adalah:

`60 px → 25 px → 0 px → 20 px → 40 px → 50 px`

Dengan urutan status yang diharapkan:

`GREEN → YELLOW → RED → YELLOW (latched) → YELLOW (latched) → GREEN/release`.

Jalankan satu siklus penuh tanpa mengubah threshold di tengah siklus. Untuk evidence yang simetris, disarankan mengambil setidaknya satu siklus lengkap pada sisi kiri dan satu pada sisi kanan. Simpan CSV Histeresis setelah selesai.

## 8. BAB IV 4.4 — Performa Real-Time CPU

Lakukan **3 run terpisah**, masing-masing 60 detik setelah kondisi visual stabil:
1. Jalur relatif kosong.
2. Satu motor pada jalur.
3. Obstacle dan lane lebih padat.

Langkah tiap run:
1. Pilih card **4.4 Performa Real-Time**.
2. Pilih Kondisi Visual yang sesuai.
3. Pastikan raw detection dan performance stream fresh.
4. Klik **START** dan jangan mengubah kondisi secara sengaja selama run.
5. GUI mencatat update aktual dan akan **AUTO STOP** sekitar 60 s.
6. Tunggu proses STOP + SAVE selesai sebelum memulai kondisi berikutnya.
7. Pastikan `SSE gap = 0` dan Status Data = VALID sebelum memakai FPS hitung sebagai hasil laporan.

Data yang direkap GUI 4.4 mencakup:
- jumlah frame event yang benar-benar diterima;
- FPS hitung dari frame event/durasi;
- mean pipeline FPS;
- mean inference time;
- mean process total;
- mean frame age;
- mean subscriber latency;
- tabel mean per detik 1–60;
- statistik mean, std, min, max, dan jumlah sampel.

Jika terdapat SSE gap atau tidak ada frame, jangan mengisi hasil dengan angka perkiraan. Ulangi run setelah sumber data stabil.

## 9. Evidence dan file yang wajib disimpan

Setelah **STOP + SAVE**, recorder saat ini menyiapkan raw/primary CSV, tabel CSV, YAML trial/rekap konfigurasi, XLSX, PNG grafik, dan manifest. Gunakan tombol artifact/download yang muncul setelah STOP.

Untuk setiap tahap final simpan:
- F4.1: screenshot/evidence runtime + parameter dump.
- F4.2: raw 200 trial, rekap DR/confidence, raw+rekap 30 frame negatif, PNG DR, PNG confidence.
- F4.3: raw 80 trial, rekap Success Rate, CSV histeresis, PNG Success Rate.
- F4.4: satu paket evidence per kondisi 60 s, tabel per detik, statistik, dan PNG time-series.

Jangan hanya menyimpan tabel rekap. Raw trial diperlukan untuk audit ulang bila dosen menanyakan asal angka.

## 10. Checklist sebelum memindahkan hasil ke laporan

Sebelum laporan dinyatakan final, pastikan:
- seluruh label **DATA ESTIMASI** pada angka hasil sudah diganti/ditandai dengan data aktual;
- tabel, grafik, dan narasi memakai dataset aktual yang sama;
- jumlah raw row cocok dengan protokol: 200 detection, 30 negative frame, 80 lane trial, dan 3 × 60 s performa;
- confidence trial gagal tetap kosong/N/A, bukan nol;
- statistik object detection tidak tercampur dengan `semantic_detections` atau `obstacle_metrics`;
- screenshot yang dipakai menunjukkan inference benar-benar ON;
- backend dan parameter efektif pada saat run tercatat;
- file export, manifest, dan parameter dump disimpan bersama sebagai evidence.

## 11. Troubleshooting cepat

**START disabled / BLOCKED**  
Baca panel Preflight. Untuk 4.2/4.4 biasanya raw detection stream belum fresh; untuk 4.3 lane stream belum fresh; seluruh tahap final juga membutuhkan YOLOPv2 CPU inference aktif.

**Obstacle Calibration tidak bisa Capture**  
Cek CAMERA HEALTHY, `semantic_detections` fresh, kelas objek benar, confidence cukup, objek berada dekat tengah citra, dan bbox tidak bottom-clipped untuk 3–5 m.

**Lane calibration menunjukkan INVALID**  
Periksa Y atas/bawah, persilangan kiri-kanan, nilai Kp, dan luas ROI. Jangan Apply sampai geometry valid.

**YAML berubah saat sedang edit**  
GUI akan menunjukkan `YAML CHANGED`. Pilih Reload untuk membuang draft atau Keep Draft jika memang ingin mempertahankan candidate, kemudian review ulang diff sebelum Stage/Apply.

**Hasil 4.4 CHECK / SSE GAP OR NO FRAME**  
Run tidak layak dipakai untuk FPS count. Stabilkan koneksi/stream lalu ulangi 60 detik; jangan mengganti nilai dengan estimasi.

---

Dokumen ini mengikuti implementasi repository NUC yang diperiksa pada 2026-09-16. Jika `perception_bab4.js`, `perception_calibration.js`, atau protokol laporan berubah, panduan harus diaudit ulang sebelum pengambilan data final.

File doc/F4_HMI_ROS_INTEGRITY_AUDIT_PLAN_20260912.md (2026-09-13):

# F4 + HMI + ROS Integrity Audit & Implementation Plan — 2026-09-12

## Baseline yang diaudit
- F4gateway branch `v1`, transport NEO3Pro/MCP2515 sudah fast-ISR + raw FIFO 128.
- ROS `stmf4_hmi_bridge` menjadi bridge F4/HMI/sensor; ESC dimiliki langsung package `esc`.
- CAN live baseline: TEC/REC/EFLG=0, RX overflow=0, protocol error=0, peer ACTIVE, DNA 2/2/2.
- Build F4 dan `stmf4` PASS; cppcheck F4+ROS menghasilkan 0 warning.

## Temuan P0 — wajib diperbaiki lebih dulu
1. **Safety STOP dari HMI masih best-effort.** `stopDriveTest()` dan `stopSteeringTest()` memakai `printBoth()` -> low-priority USB ring; kegagalan enqueue diabaikan.
2. **ROS manual drive tidak punya command lease/deadman.** Setelah `drive_=FWD/REV`, `commandTick()` terus publish selama gate umum masih valid. STOP yang hilang saat USB congestion dapat memperpanjang motion.
3. **Safety gate ROS lebih longgar daripada F4.** `/hmi/request` dari Web dapat MODE/DRIVE/STEER langsung; `manualMotionAllowed()` tidak menguji state awal/stationary seperti F4 HMI.
4. **Waypoint GO tidak fail-closed lengkap.** `goWaypoint()` hanya saved+AUTO; belum wajib E-stop clear, motion_ready, nav2_ready, fresh map localization, dan finite persisted waypoint.
5. **Nav cancel memblok single-thread executor sampai 250 ms.** `wait_for_service(250ms)` dapat menahan serial F4/heartbeat saat Nav2 tidak siap.

## Temuan P1 — state/contract integrity
6. ROS selalu mengirim `NEO:LED:AUTO` saat reconnect, tetapi NEO3PRO firmware tidak mendukung AUTO; menghasilkan `ERR:NEO:LED:ARGS`.
7. `/neo3/command` menawarkan command legacy (AUTO/ON/BEEP/BUZZER) yang tidak sama dengan command set NEO3PRO.
8. `closeSerial()` tidak meng-invalidasi semua cached NEO3PRO health/wire/time state; transient-local diagnostic string dapat menyisakan health lama setelah disconnect.
9. MCU timestamp epoch dan per-stream wire sequence tidak di-reset eksplisit pada host-session baru; rapid reboot dapat membuat packet pertama dianggap duplicate/out-of-order dan timestamp sementara ter-clamp.
10. Absolute GNSS time bridge menerima formula TAI/GPS custom; ArduPilot reference hanya menggunakan absolute timestamp saat standard=UTC.
11. `publishHardware()` masih melakukan read TEC/REC/EFLG SPI2 lagi; health service sudah bisa menjadi satu-satunya sampler/cache.
12. `writeLineCritical()` memakai `HAL_Delay(1)` dan `flush()` busy-poll; keduanya belum cooperative-yield ke realtime service.

## Temuan P1/P2 — HMI, diagnostics, CI
13. HMI diagnostic fields masih overload nama legacy VESC (`pb6VescTx/pb7VescRx`) untuk MCP pins; raw source benar tetapi contract membingungkan.
14. `SYSTEM_ERRORS` belum menampilkan raw FIFO HWM/overflow, USB high-priority drops, peer state, DNA fault, dan host session freshness.
15. F4 production `F4_ESC_GATEWAY=0`, tetapi ROS bridge masih menyimpan dead legacy VESC transport code/members; test lama masih menganggap F4↔F103 aktif.
16. `hmi_10repo_audit_self_check.py` masih menuntut visible `vescFrameErrors` walaupun ESC bukan domain F4 lagi.
17. `recovery_state_machine_self_check.py` masih mengharapkan manifest v1; bootloader/generator production sudah manifest v2 + board ID.
18. `stmf4_gateway_self_check.py` masih mengharapkan `vesc_uart_baud_expected` dan layout flash lama; test contract tidak lagi mewakili architecture production.
19. Waypoint persistence belum memvalidasi finite/range saat load dan belum durability-grade fsync+rename; file korup dapat menghasilkan goal invalid bila tidak ditutup.
20. `stmf4_hmi_bridge.cpp` sangat monolitik (~166 kB source), sehingga perubahan sensor/HMI/control mudah saling memengaruhi dan regression coverage sulit dipetakan.
21. CAN TX masih hanya TXB0 + status polling SPI. Normal runtime sekarang zero-loss, jadi ini optimasi P2, bukan blocker.
22. HMI full redraw pernah mencapai ratusan ms; realtime CAN aman karena yield, tetapi touch/UI latency perlu budget dan qualification tersendiri.

# TAHAP 1 — Safety + contract + state integrity
### 1. Safety transport F4→ROS
- Buat `sendControlHighPriority()` terpisah dari telemetry `printBoth()`.
- Semua STOP (`DRIVE`, `STEER`, `NAV`) wajib high-priority dan return value tidak boleh diabaikan.
- Tambah latched `pending_stop` yang di-retry tiap loop sampai berhasil enqueue/session hilang.
- Pisahkan counter `control_tx_drop`, `stop_retry`, `stop_ack_timeout` dari low-priority telemetry drops.
- `writeLineCritical()` tidak boleh HAL_Delay; gunakan cooperative realtime service/yield bounded.

### 2. Manual command lease/deadman di ROS
- FWD/REV/steering hanya aktif jika lease HMI fresh (target 250–350 ms).
- F4 saat HOLD mengirim heartbeat/lease control periodik, bukan hanya satu state transition.
- Timeout lease, CDC disconnect, mode change, E-stop, ESC stale, atau source ownership berubah => publish zero + source STOP pada tick berikutnya.
- Start manual harus stationary/fresh; setelah lease aktif controller boleh bergerak sesuai bounded command.

### 3. Satu safety gate untuk TFT + Web
- Buat satu fungsi `manualRequestAllowed(origin, action)` yang dipakai TFT dan `/hmi/request`.
- Jangan biarkan Web bypass stationary/start interlock F4.
- MODE:MANUAL dari Web/TFT tidak otomatis memberi motion authority.
- Validasi active-source/mux ownership sebelum nonzero HMI cmd_vel diterbitkan.

### 4. Navigation mission gate
- `goWaypoint()` wajib: connected, AUTO, E-stop clear, waypoint finite+saved, `motion_ready`, `nav2_ready`, fresh `/odometry/filtered_map`, dan localization acceptable.
- Reject dengan reason eksplisit; jangan publish goal lalu berharap downstream menolak.
- `stopNavigation()` dibuat nonblocking: tidak ada `wait_for_service()` di executor callback; gunakan cached service readiness/async retry.
- Load waypoint: reject NaN/Inf/out-of-range; invalid record menjadi unsaved.
- Persistence: temp file -> flush/fsync -> atomic rename -> optional directory fsync.

### 5. Session/state invalidation ROS
- Saat `closeSerial()`: reset NEO3PRO active/health/meta/covariance/wire-sequence/MCU-clock epoch dan publish connected=false.
- Raw diagnostic transient-local topics harus mendapat sentinel `DISCONNECTED,session=...` atau dijadikan volatile; subscriber baru tidak boleh melihat stale ACTIVE tanpa connected context.
- Saat host-session ACK baru: mulai epoch baru, clear per-stream wire state dan timestamp mapper secara deterministik.

### 6. NEO command contract
- Hapus side effect `NEO:LED:AUTO` dari initial session.
- NEO3PRO startup hanya `STATUS/USB STATUS`; jangan mengubah LED/parameter saat reconnect.
- Buat allowlist profile-specific command: STATUS, CAN STATUS/RECOVER, BARO, LED BRIGHTNESS/RGB/OFF.
- Legacy BEEP/BUZZER/AUTO hanya tersedia pada profile yang benar-benar mendukungnya.
- Tambah contract self-check ROS↔F4 agar command tidak bisa drift lagi.

### 7. CAN/USB low-level cleanup tanpa mengubah RX architecture
- Cache TEC/REC/EFLG di `serviceCanHealth()`; `publishHardware()` hanya membaca cache, sehingga diagnostics tidak menambah SPI2 contention.
- Pertahankan PB10 fast ISR + raw FIFO 128 + main-context libcanard.
- Rapikan komentar TXEP/bus-off agar sesuai behavior aktual.
- Ubah `flush()` menjadi bounded cooperative flush yang tetap menjalankan realtime service.

# TAHAP 2 — HMI diagnostics, refactor, qualification
### 8. HMI observability dan latency
- Ganti alias pin legacy dengan field MCP khusus: INT/CS/SCK/MISO/MOSI.
- SYSTEM_ERRORS tampilkan MCP overflow, SW FIFO HWM/overflow, ISR max/budget, USB high-priority drop, peer state, DNA fault, host session/generation.
- Bedakan historical counter vs delta-since-session agar operator tidak salah membaca fault lama.
- Ukur full-frame dan dirty-frame p50/p95/p99; optimasi hanya renderer yang nyata mahal.
- Target touch action-to-visible response terukur dan tidak mengurangi CAN service density.

### 9. Bersihkan architecture ROS
- Hapus dead VESC-over-F4 methods/members/subscriptions dari `stmf4`; ESC hanya direct package `esc`.
- Pecah bridge bertahap menjadi SerialTransport, Neo3Protocol, HmiControlSafety, NavigationGateway, ExtendedTelemetry.
- Refactor harus behavior-preserving dan dilakukan setelah P0 tests tersedia.
- Parameter safety/protocol (`neo3_require_protocol_crc`, `neo3_safety_button_as_estop`, baro frame id) ditulis eksplisit di YAML.

### 10. Timestamp parity ArduPilot
- Untuk Fix2 absolute timestamp, gunakan epoch GNSS hanya bila `gnss_time_standard == UTC`, sama seperti AP_GPS_DroneCAN.
- NONE/TAI/GPS yang belum tervalidasi DSDL-test harus fallback ke MCU/reception time, bukan conversion custom tanpa proof.
- Tambah test UTC, invalid leap, clock disagreement, F4 reboot <5 s, wrap uint32 ms.
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

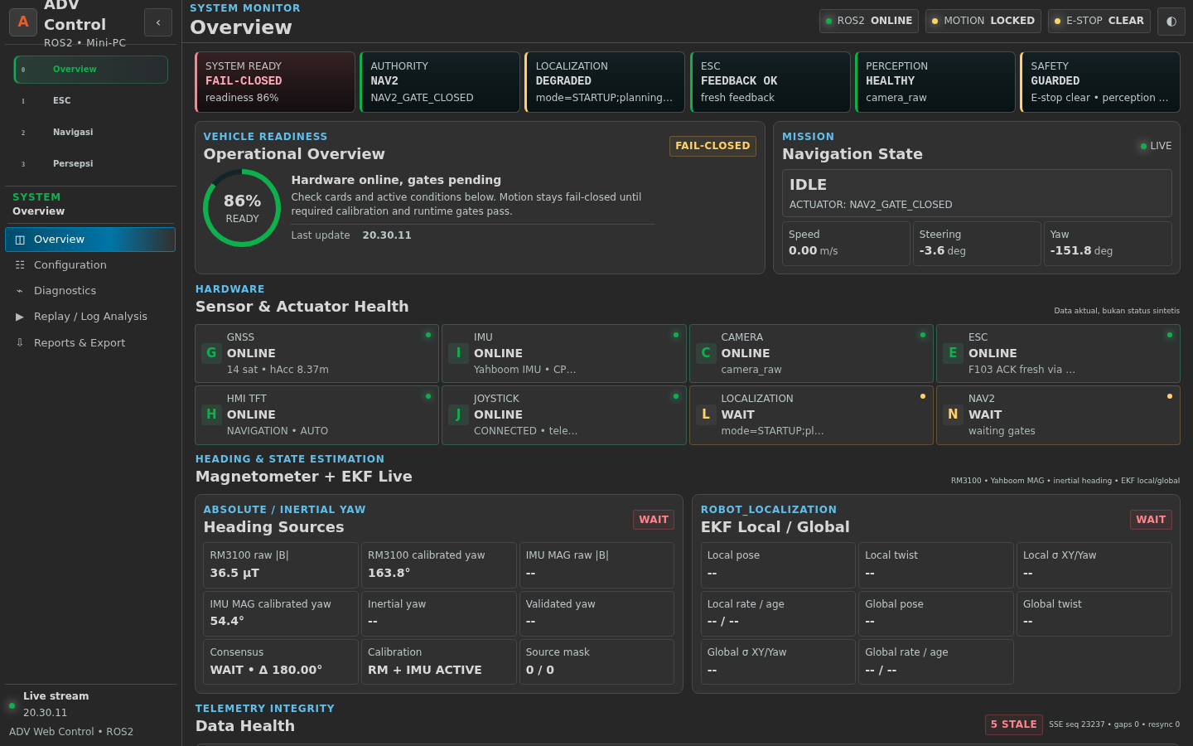
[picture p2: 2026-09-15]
.ui_audit/audit-overview-desktop.png

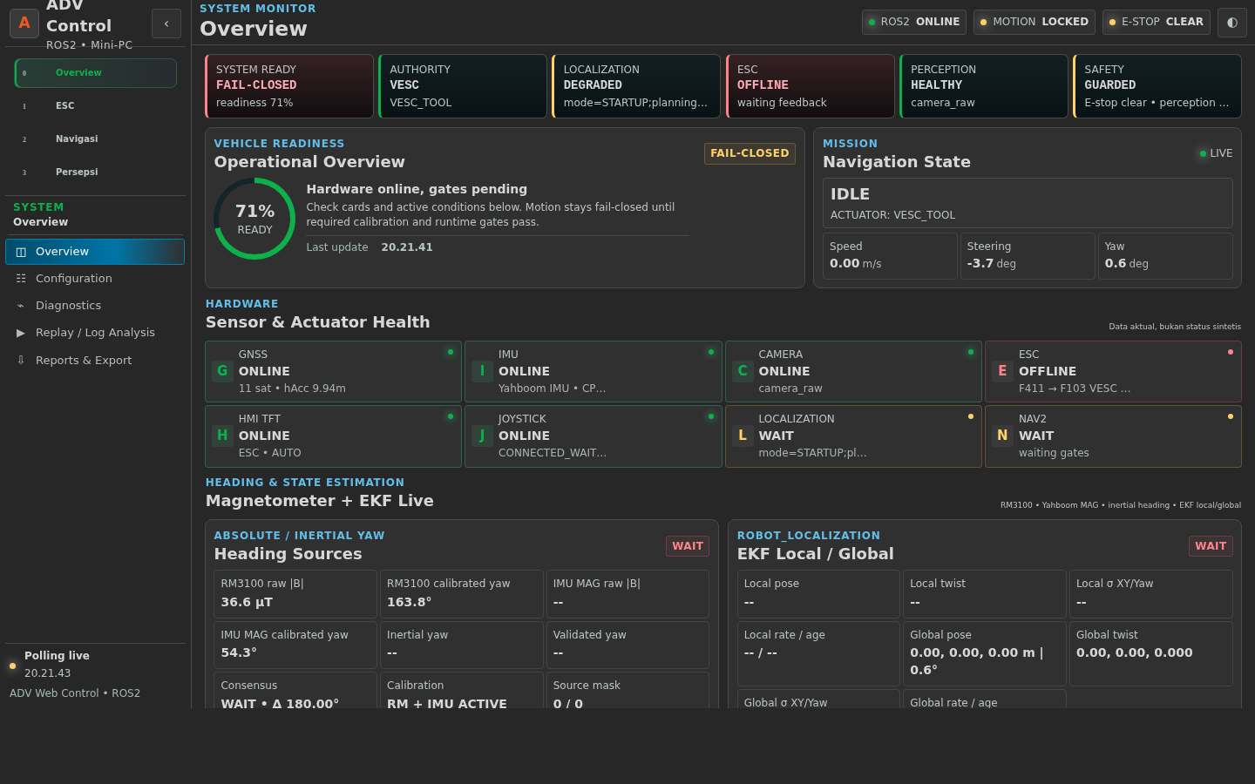
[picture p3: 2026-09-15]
.ui_audit/before-overview-1440.png

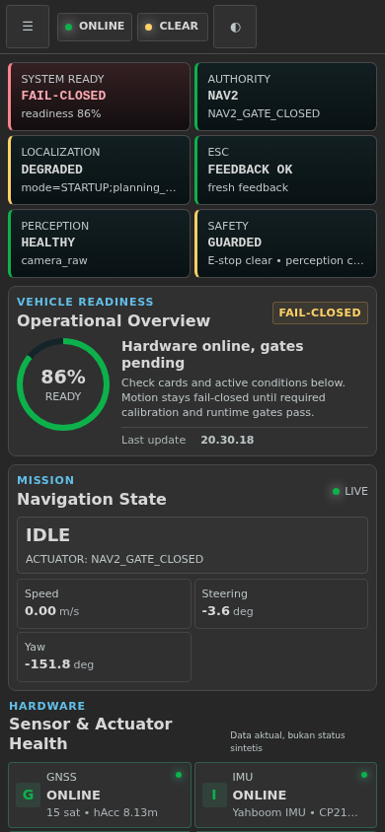
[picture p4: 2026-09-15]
.ui_audit/audit-overview-mobile.png

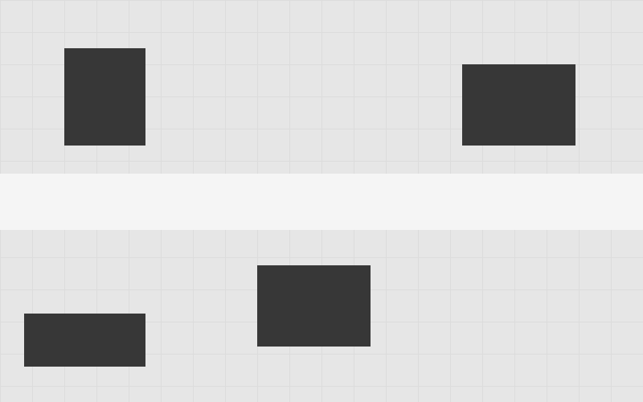
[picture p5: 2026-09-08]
.preview_v3/api/map.png

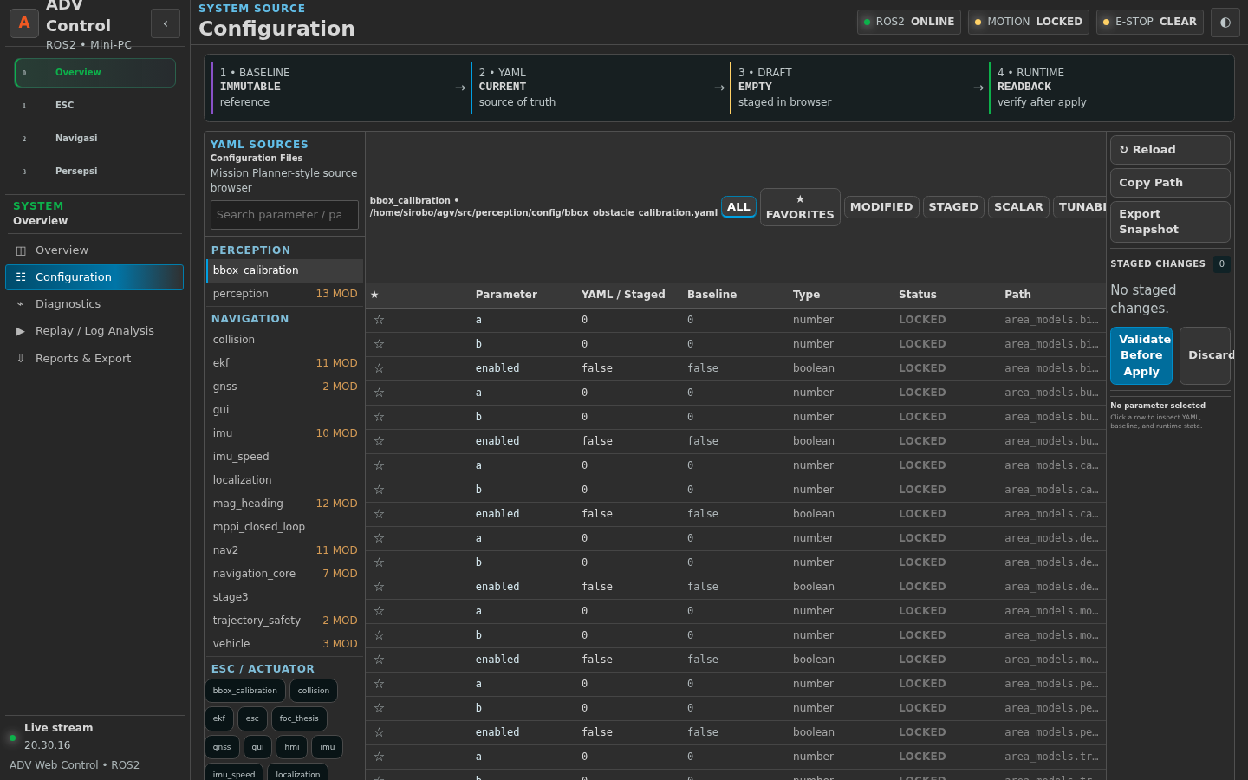
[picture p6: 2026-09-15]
.ui_audit/audit-configuration-desktop.png

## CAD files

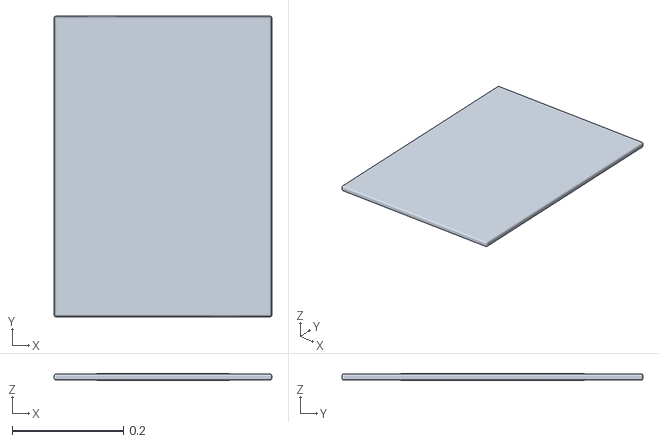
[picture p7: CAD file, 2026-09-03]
src/navigation/urdf/meshes/wood_lid.stl
0.392 x 0.542 x 0.012

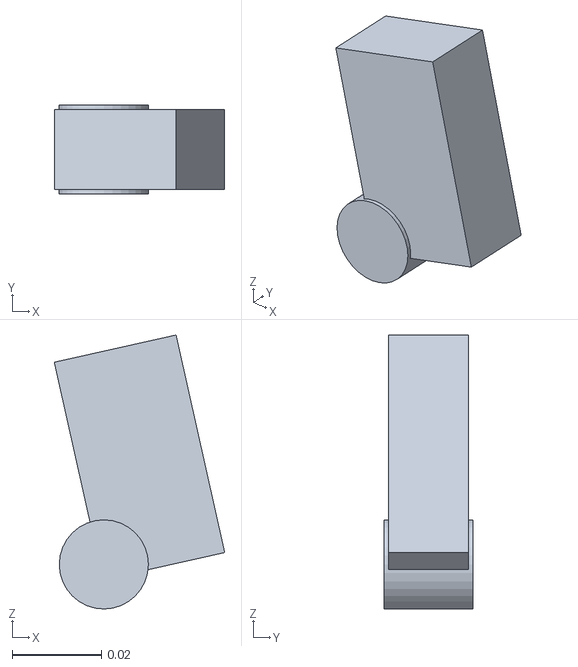
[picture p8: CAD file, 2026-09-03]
src/navigation/urdf/meshes/chassis_caliper.stl
0.0382 x 0.02 x 0.0615

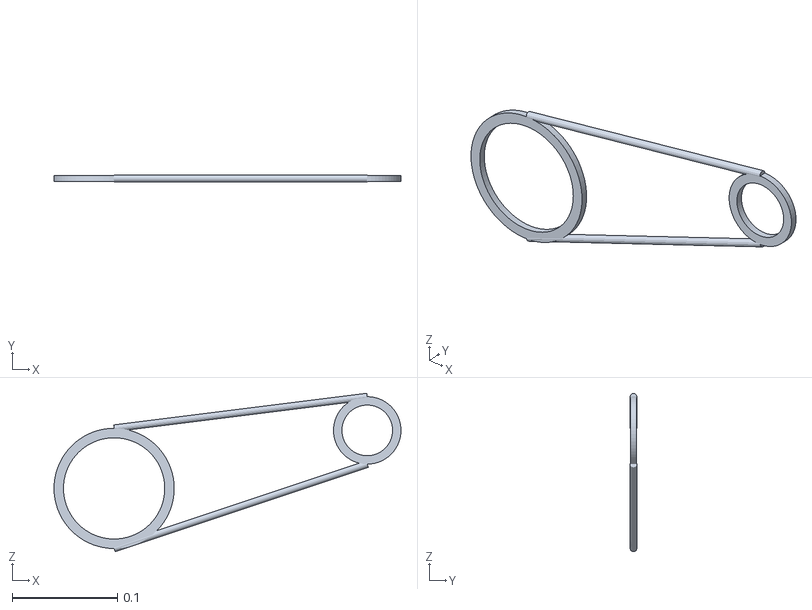
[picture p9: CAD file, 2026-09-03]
src/navigation/urdf/meshes/chassis_chain.stl
0.329 x 0.0064 x 0.15

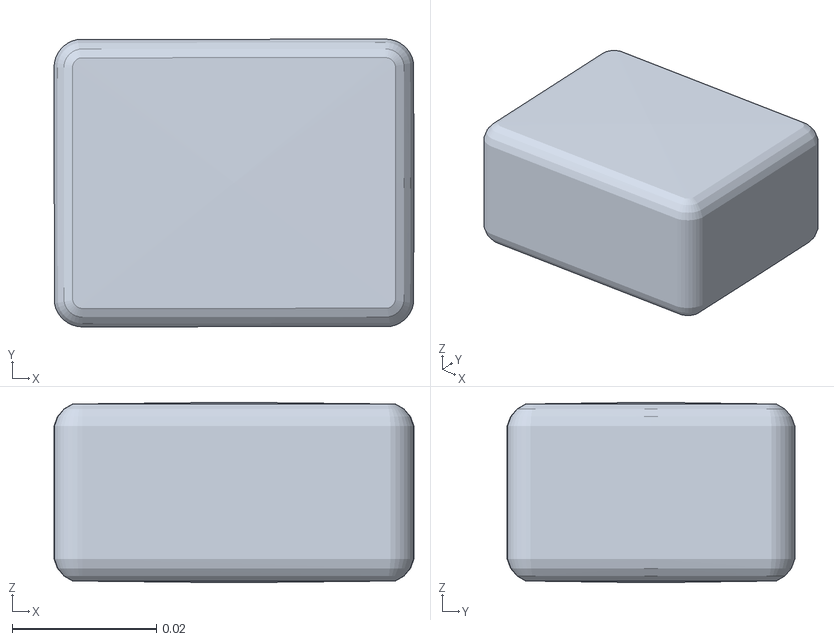
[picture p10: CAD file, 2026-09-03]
src/navigation/urdf/meshes/imu_case.stl
0.0499 x 0.0399 x 0.025

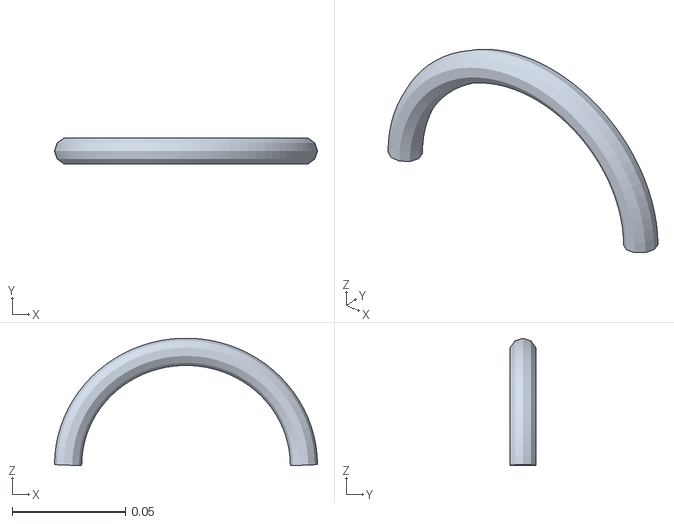
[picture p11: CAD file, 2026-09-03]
src/navigation/urdf/meshes/water_jug_handle.stl
0.116 x 0.0114 x 0.0562

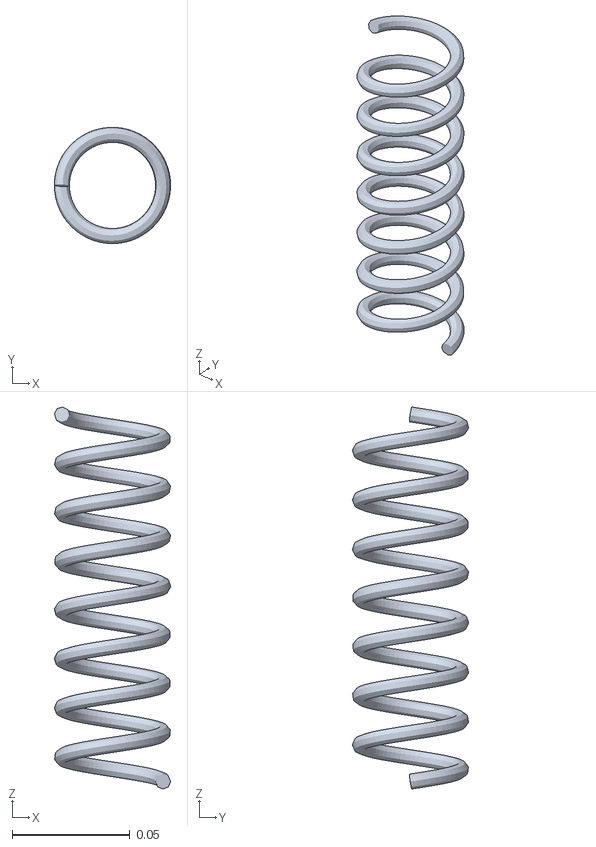
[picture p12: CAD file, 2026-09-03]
src/navigation/urdf/meshes/coil_spring.stl
0.0494 x 0.0494 x 0.162

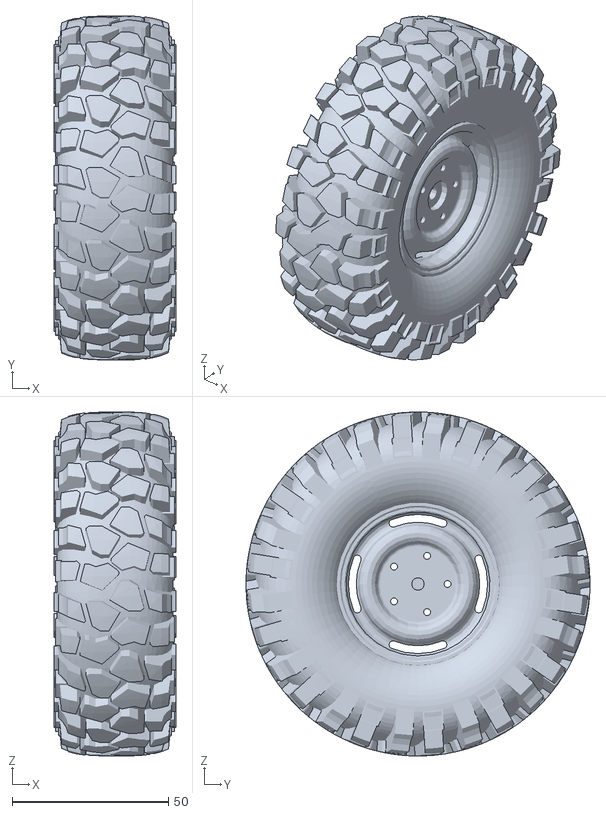
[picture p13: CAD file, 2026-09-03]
src/navigation/urdf/meshes/wheel.stl
39.0 x 110.0 x 110.0

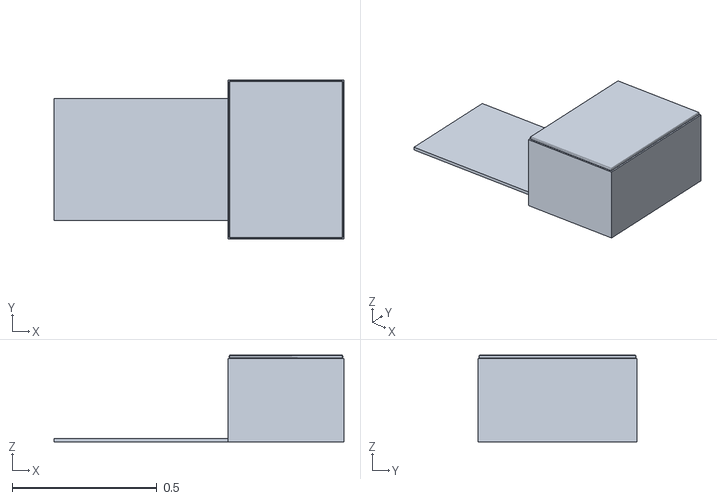
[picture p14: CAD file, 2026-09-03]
src/navigation/urdf/meshes/chassis_wood.stl
1.00 x 0.55 x 0.3

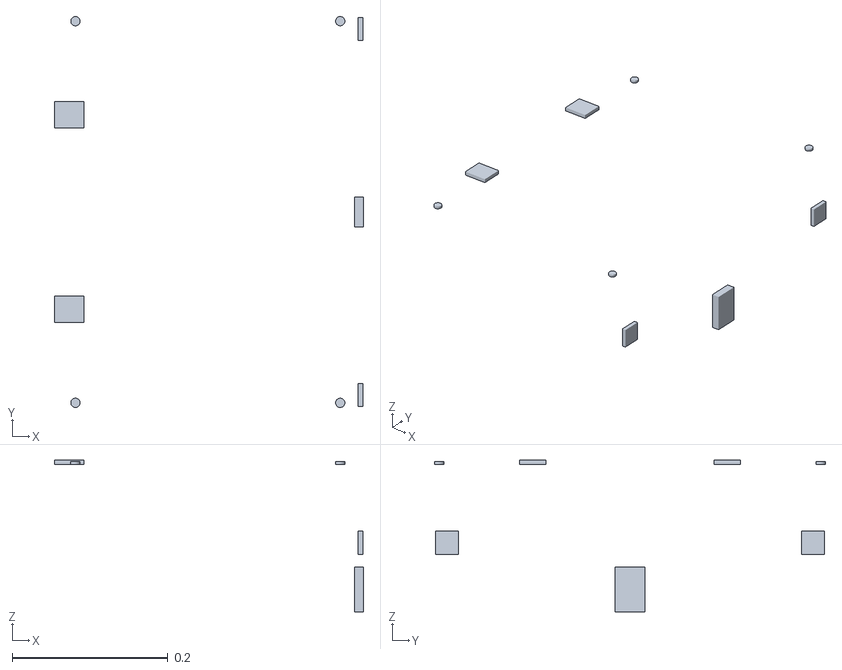
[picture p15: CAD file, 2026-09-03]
src/navigation/urdf/meshes/chassis_hardware.stl
0.397 x 0.502 x 0.195

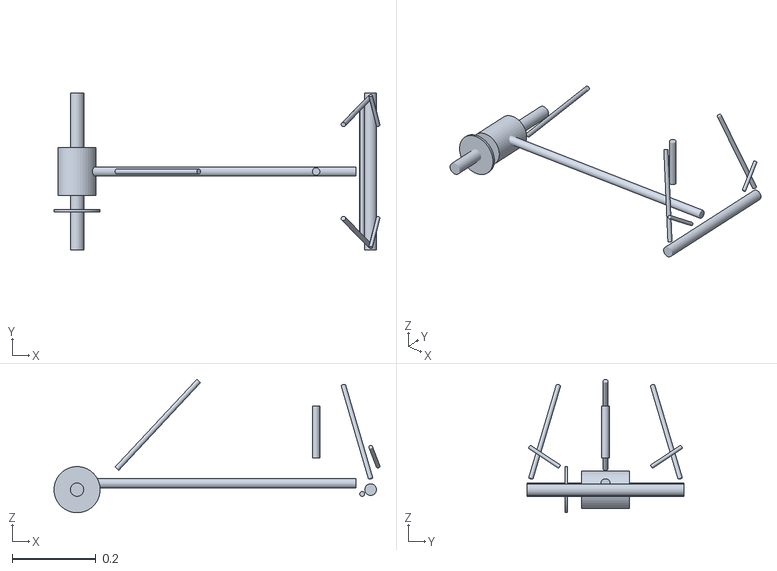
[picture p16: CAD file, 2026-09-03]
src/navigation/urdf/meshes/chassis_silver.stl
0.777 x 0.374 x 0.318

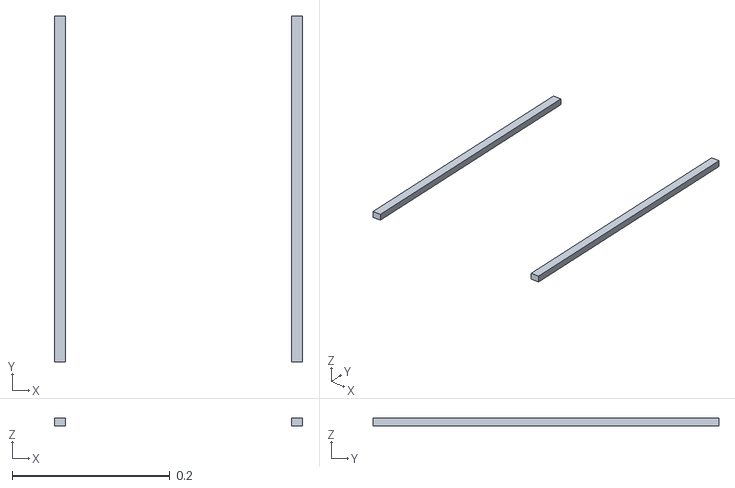
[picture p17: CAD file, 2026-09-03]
src/navigation/urdf/meshes/chassis_straps.stl
0.314 x 0.438 x 0.01

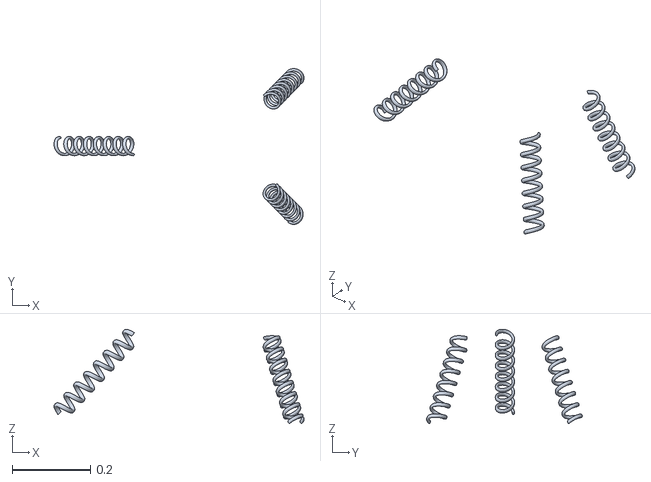
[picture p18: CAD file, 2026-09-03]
src/navigation/urdf/meshes/chassis_spring.stl
0.637 x 0.397 x 0.241

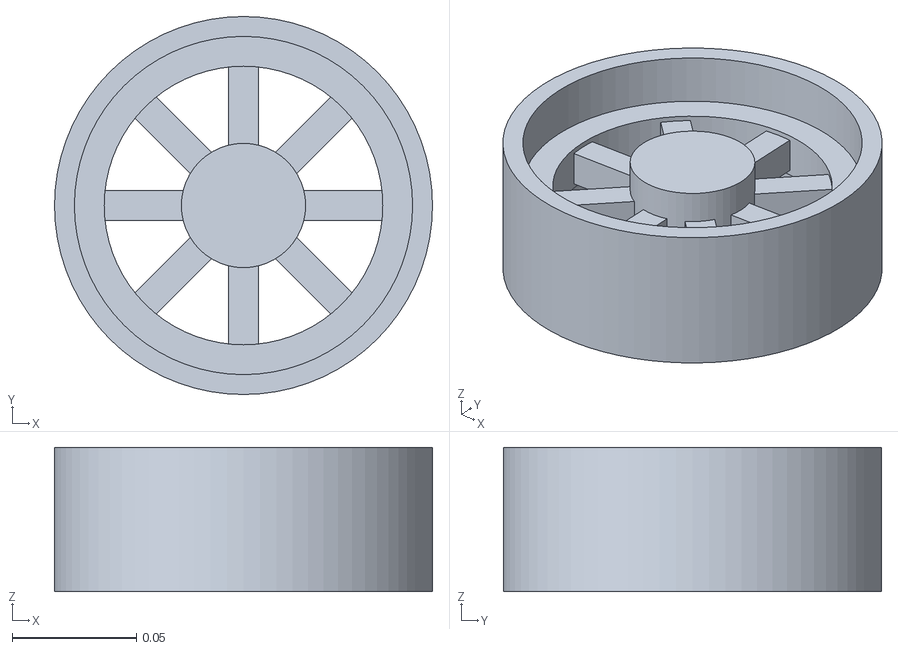
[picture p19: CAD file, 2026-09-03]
src/navigation/urdf/meshes/atv_rim.stl
0.152 x 0.152 x 0.058

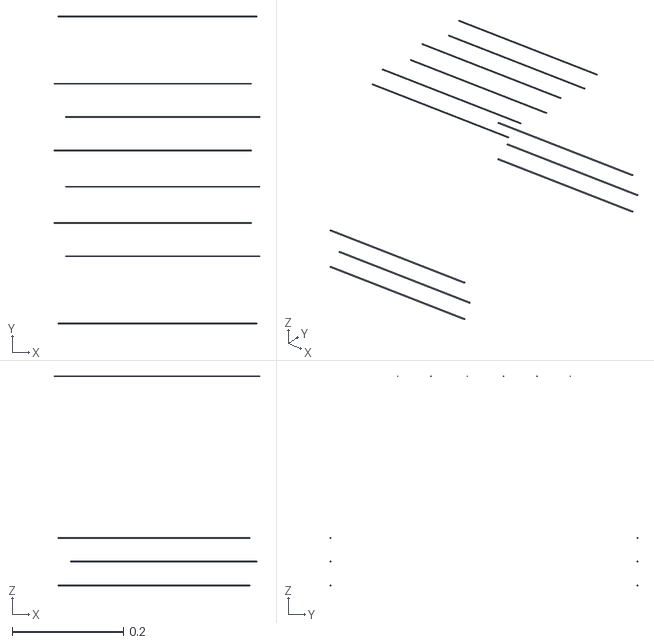
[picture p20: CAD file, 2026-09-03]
src/navigation/urdf/meshes/chassis_wood_grain.stl
0.37 x 0.552 x 0.377

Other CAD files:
src/navigation/urdf/meshes/camera_astra_pro.stl
src/navigation/urdf/meshes/gnss_dome.stl
src/navigation/urdf/meshes/water_jug_detail.stl
src/navigation/urdf/meshes/water_jug_19l.stl
src/navigation/urdf/meshes/chassis_black.stl
src/navigation/urdf/meshes/chassis_galvanized.stl
src/navigation/urdf/meshes/hmi_case.stl

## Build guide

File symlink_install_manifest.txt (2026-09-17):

/home/sirobo/agv/install/navigation/lib/navigation/gnss_node
/home/sirobo/agv/install/navigation/lib/navigation/imu_node
/home/sirobo/agv/install/navigation/lib/navigation/imu_speed_diagnostic
/home/sirobo/agv/install/navigation/lib/navigation/mag_heading_fusion
/home/sirobo/agv/install/navigation/lib/navigation/joint_state_visualizer
/home/sirobo/agv/install/navigation/lib/navigation/localization_core
/home/sirobo/agv/install/navigation/lib/navigation/precision_localization_monitor
/home/sirobo/agv/install/navigation/lib/navigation/cmd_vel_router
/home/sirobo/agv/install/navigation/lib/navigation/sensor_contract_monitor
/home/sirobo/agv/install/navigation/lib/navigation/navigation_core
/home/sirobo/agv/install/navigation/lib/navigation/mppi_closed_loop_supervisor
/home/sirobo/agv/install/navigation/lib/navigation/vehicle_dynamics_observer
/home/sirobo/agv/install/navigation/lib/navigation/trajectory_safety_supervisor
/home/sirobo/agv/install/navigation/lib/navigation/global_field_test_localizer
/home/sirobo/agv/install/navigation/lib/navigation/global_test_odom_bridge
/home/sirobo/agv/install/navigation/lib/navigation/agv_gui
/home/sirobo/agv/install/navigation/lib/navigation/agv_web_gui
/home/sirobo/agv/install/navigation/share/navigation/launch/__pycache__/autonomous.launch.cpython-310.pyc
/home/sirobo/agv/install/navigation/share/navigation/launch/__pycache__/gui.launch.cpython-310.pyc
/home/sirobo/agv/install/navigation/share/navigation/launch/__pycache__/web_gui.launch.cpython-310.pyc
/home/sirobo/agv/install/navigation/share/navigation/launch/autonomous.launch.py
/home/sirobo/agv/install/navigation/share/navigation/launch/global_field_test.launch.py
/home/sirobo/agv/install/navigation/share/navigation/launch/gnss.launch.py
/home/sirobo/agv/install/navigation/share/navigation/launch/gui.launch.py
/home/sirobo/agv/install/navigation/share/navigation/launch/imu.launch.py
/home/sirobo/agv/install/navigation/share/navigation/launch/urdf_rviz.launch.py
/home/sirobo/agv/install/navigation/share/navigation/launch/web_gui.launch.py
/home/sirobo/agv/install/navigation/share/navigation/config/absolute_localization.yaml
/home/sirobo/agv/install/navigation/share/navigation/config/collision_monitor.yaml
/home/sirobo/agv/install/navigation/share/navigation/config/collision_monitor_preview.yaml
/home/sirobo/agv/install/navigation/share/navigation/config/collision_monitor_production.yaml
/home/sirobo/agv/install/navigation/share/navigation/config/collision_monitor_production.yaml.web.baseline
/home/sirobo/agv/install/navigation/share/navigation/config/ekf.yaml
/home/sirobo/agv/install/navigation/share/navigation/config/ekf.yaml.web.baseline
/home/sirobo/agv/install/navigation/share/navigation/config/ekf_global_field_test.yaml
/home/sirobo/agv/install/navigation/share/navigation/config/fastdds_no_shm.xml
/home/sirobo/agv/install/navigation/share/navigation/config/global_field_test.yaml
/home/sirobo/agv/install/navigation/share/navigation/config/gnss.yaml
/home/sirobo/agv/install/navigation/share/navigation/config/gnss.yaml.web.baseline
/home/sirobo/agv/install/navigation/share/navigation/config/gui_calibration.yaml
/home/sirobo/agv/install/navigation/share/navigation/config/gui_calibration.yaml.web.baseline
/home/sirobo/agv/install/navigation/share/navigation/config/imu.yaml
/home/sirobo/agv/install/navigation/share/navigation/config/imu.yaml.web.baseline
/home/sirobo/agv/install/navigation/share/navigation/config/imu_calibration.yaml
/home/sirobo/agv/install/navigation/share/navigation/config/imu_speed.yaml
/home/sirobo/agv/install/navigation/share/navigation/config/imu_speed.yaml.web.baseline
/home/sirobo/agv/install/navigation/share/navigation/config/localization_cpp.yaml
/home/sirobo/agv/install/navigation/share/navigation/config/localization_cpp.yaml.web.baseline
/home/sirobo/agv/install/navigation/share/navigation/config/mag_heading.yaml
/home/sirobo/agv/install/navigation/share/navigation/config/mag_heading.yaml.web.baseline
/home/sirobo/agv/install/navigation/share/navigation/config/mppi_closed_loop.yaml
/home/sirobo/agv/install/navigation/share/navigation/config/mppi_closed_loop.yaml.web.baseline
/home/sirobo/agv/install/navigation/share/navigation/config/nav2_ackermann.yaml
/home/sirobo/agv/install/navigation/share/navigation/config/nav2_ackermann.yaml.web.baseline
/home/sirobo/agv/install/navigation/share/navigation/config/navigation_core.yaml
/home/sirobo/agv/install/navigation/share/navigation/config/navigation_core.yaml.web.baseline
/home/sirobo/agv/install/navigation/share/navigation/config/precision.yaml
/home/sirobo/agv/install/navigation/share/navigation/config/saved_targets.yaml
/home/sirobo/agv/install/navigation/share/navigation/config/stage3_navigation.yaml
/home/sirobo/agv/install/navigation/share/navigation/config/stage3_navigation.yaml.web.baseline
/home/sirobo/agv/install/navigation/share/navigation/config/trajectory_safety.yaml
/home/sirobo/agv/install/navigation/share/navigation/config/trajectory_safety.yaml.web.baseline
/home/sirobo/agv/install/navigation/share/navigation/config/vehicle.yaml
/home/sirobo/agv/install/navigation/share/navigation/config/vehicle.yaml.web.baseline
/home/sirobo/agv/install/navigation/share/navigation/rviz/autonomous.rviz
/home/sirobo/agv/install/navigation/share/navigation/rviz/global_field_test.rviz
/home/sirobo/agv/install/navigation/share/navigation/rviz/urdf.rviz
/home/sirobo/agv/install/navigation/share/navigation/urdf/agv.urdf.xacro
/home/sirobo/agv/install/navigation/share/navigation/urdf/chassis.xacro
/home/sirobo/agv/install/navigation/share/navigation/urdf/dimensions.xacro
/home/sirobo/agv/install/navigation/share/navigation/urdf/joints.xacro
/home/sirobo/agv/install/navigation/share/navigation/urdf/materials.xacro
/home/sirobo/agv/install/navigation/share/navigation/urdf/meshes/atv_rim.stl
/home/sirobo/agv/install/navigation/share/navigation/urdf/meshes/camera_astra_pro.stl
/home/sirobo/agv/install/navigation/share/navigation/urdf/meshes/chassis_black.stl
/home/sirobo/agv/install/navigation/share/navigation/urdf/meshes/chassis_caliper.stl
/home/sirobo/agv/install/navigation/share/navigation/urdf/meshes/chassis_chain.stl
/home/sirobo/agv/install/navigation/share/navigation/urdf/meshes/chassis_galvanized.stl
/home/sirobo/agv/install/navigation/share/navigation/urdf/meshes/chassis_hardware.stl
/home/sirobo/agv/install/navigation/share/navigation/urdf/meshes/chassis_silver.stl
/home/sirobo/agv/install/navigation/share/navigation/urdf/meshes/chassis_spring.stl
/home/sirobo/agv/install/navigation/share/navigation/urdf/meshes/chassis_straps.stl
/home/sirobo/agv/install/navigation/share/navigation/urdf/meshes/chassis_wood.stl
/home/sirobo/agv/install/navigation/share/navigation/urdf/meshes/chassis_wood_grain.stl
/home/sirobo/agv/install/navigation/share/navigation/urdf/meshes/coil_spring.stl
/home/sirobo/agv/install/navigation/share/navigation/urdf/meshes/gnss_dome.stl
/home/sirobo/agv/install/navigation/share/navigation/urdf/meshes/hmi_case.stl
/home/sirobo/agv/install/navigation/share/navigation/urdf/meshes/imu_case.stl
/home/sirobo/agv/install/navigation/share/navigation/urdf/meshes/water_jug_19l.stl
/home/sirobo/agv/install/navigation/share/navigation/urdf/meshes/water_jug_detail.stl
/home/sirobo/agv/install/navigation/share/navigation/urdf/meshes/water_jug_handle.stl
/home/sirobo/agv/install/navigation/share/navigation/urdf/meshes/wheel.stl
/home/sirobo/agv/install/navigation/share/navigation/urdf/meshes/wood_lid.stl
/home/sirobo/agv/install/navigation/share/navigation/urdf/sensors.xacro
/home/sirobo/agv/install/navigation/share/navigation/urdf/steering.xacro
/home/sirobo/agv/install/navigation/share/navigation/urdf/suspension.xacro
/home/sirobo/agv/install/navigation/share/navigation/urdf/visual_drivetrain.xacro
/home/sirobo/agv/install/navigation/share/navigation/urdf/water_jugs.xacro
/home/sirobo/agv/install/navigation/share/navigation/urdf/wheels.xacro
/home/sirobo/agv/install/navigation/share/navigation/maps/undip/undip_nav2.pgm
/home/sirobo/agv/install/navigation/share/navigation/maps/undip/undip_nav2.yaml
/home/sirobo/agv/install/navigation/share/navigation/maps/undip/undip_nav2_raw.osm
/home/sirobo/agv/install/navigation/share/navigation/behavior_trees/ackermann_navigate_to_pose.xml
/home/sirobo/agv/install/navigation/share/navigation/docs/GNSS_DRIVER_V2_PART1.md
/home/sirobo/agv/install/navigation/share/navigation/docs/GNSS_DRIVER_V2_PART1_VALIDATION.txt
/home/sirobo/agv/install/navigation/share/navigation/docs/GNSS_GLOBAL_FUSION_PART3.md
/home/sirobo/agv/install/navigation/share/navigation/docs/GNSS_GLOBAL_FUSION_PART3_VALIDATION.txt
/home/sirobo/agv/install/navigation/share/navigation/docs/GNSS_MOTION_VALIDATION_PART2.md
/home/sirobo/agv/install/navigation/share/navigation/docs/GNSS_MOTION_VALIDATION_PART2_VALIDATION.txt
/home/sirobo/agv/install/navigation/share/navigation/docs/GUI_CPP_FINAL_VALIDATION.txt
/home/sirobo/agv/install/navigation/share/navigation/docs/GUI_CPP_MIGRATION_V1.md
/home/sirobo/agv/install/navigation/share/navigation/docs/GUI_NAV2_EMBEDDED.md
/home/sirobo/agv/install/navigation/share/navigation/docs/HUMBLE_BUILD_FIX_20260822.md
/home/sirobo/agv/install/navigation/share/navigation/docs/MINIPC_NAV2_AUDIT_20260824.md
/home/sirobo/agv/install/navigation/share/navigation/docs/MINIPC_NAV2_NO_CAMERA_COMMISSIONING.md
/home/sirobo/agv/install/navigation/share/navigation/docs/MINIPC_NAV2_STATIC_VALIDATION_20260824.txt
/home/sirobo/agv/install/navigation/share/navigation/docs/PART2_VALIDATION.txt
/home/sirobo/agv/install/navigation/share/navigation/docs/PART3_VALIDATION.txt
/home/sirobo/agv/install/navigation/share/navigation/docs/PRECISION_REVISION_PART1.md
/home/sirobo/agv/install/navigation/share/navigation/docs/PRECISION_REVISION_PART2.md
/home/sirobo/agv/install/navigation/share/navigation/docs/PRECISION_REVISION_PART3.md
/home/sirobo/agv/install/navigation/share/navigation/docs/PRECISION_REVISION_V9.md
/home/sirobo/agv/install/navigation/share/navigation/docs/PROJECT_AUDIT_GNSS_IMU_ACKERMANN_PROLIFIC_20260823.md
/home/sirobo/agv/install/navigation/share/navigation/docs/STAGE1_COMMISSIONING.md
/home/sirobo/agv/install/navigation/share/navigation/docs/STAGE2_GNSS_IMU_ODOMETRY_FUSION.md
/home/sirobo/agv/install/navigation/share/navigation/docs/STAGE3_IMPLEMENTATION_REPORT_20260823.md
/home/sirobo/agv/install/navigation/share/navigation/docs/STAGE3_NAV2_ACKERMANN_OUTDOOR_SAFETY.md
/home/sirobo/agv/install/navigation/share/navigation/docs/STAGE3_VALIDATION_20260823.txt
/home/sirobo/agv/install/navigation/share/navigation/docs/STATIC_VALIDATION_20260823.txt
/home/sirobo/agv/install/navigation/share/navigation/docs/STEERING_PHYSICAL_CALIBRATION_PART1.md
/home/sirobo/agv/install/navigation/share/navigation/docs/STEERING_PHYSICAL_CALIBRATION_PART2.md
/home/sirobo/agv/install/navigation/share/navigation/docs/STEERING_PHYSICAL_CALIBRATION_PART3.md
/home/sirobo/agv/install/navigation/share/navigation/docs/STEERING_PHYSICAL_PART1_VALIDATION.txt
/home/sirobo/agv/install/navigation/share/navigation/docs/STEERING_PHYSICAL_PART2_VALIDATION.txt
/home/sirobo/agv/install/navigation/share/navigation/docs/STEERING_PHYSICAL_PART3_VALIDATION.txt
/home/sirobo/agv/install/navigation/share/navigation/docs/WEB_GUI_AND_USB_ROUTING_20260902.md
/home/sirobo/agv/install/navigation/share/navigation/docs/gui_interface.md
/home/sirobo/agv/install/navigation/share/navigation/docs/nav2_gui_layout.svg
/home/sirobo/agv/install/navigation/share/navigation/docs/trajectory_safety_integration.md
/home/sirobo/agv/install/navigation/share/navigation/tools/certification_manifest.py
/home/sirobo/agv/install/navigation/share/navigation/tools/experiment_rank.py
/home/sirobo/agv/install/navigation/share/navigation/tools/export_trial_artifacts.py
/home/sirobo/agv/install/navigation/share/navigation/tools/minipc_nav2_preflight.py
/home/sirobo/agv/install/navigation/share/navigation/tools/nav2_gui_flow_check.sh
/home/sirobo/agv/install/navigation/share/navigation/tools/navigation_calibration.py
/home/sirobo/agv/install/navigation/share/navigation/tools/navigation_fault_suite.py
/home/sirobo/agv/install/navigation/share/navigation/tools/navigation_field_campaign.py
/home/sirobo/agv/install/navigation/share/navigation/tools/navigation_metrics.py
/home/sirobo/agv/install/navigation/share/navigation/tools/osm_pgm.py
/home/sirobo/agv/install/navigation/share/navigation/tools/planar_eskf_ab.py
/home/sirobo/agv/install/navigation/share/navigation/tools/rm3100_ardupilot_calibration.py
/home/sirobo/agv/install/navigation/share/navigation/tools/rosbag_regression.py
/home/sirobo/agv/install/navigation/share/navigation/tools/runtime_profile.py
/home/sirobo/agv/install/navigation/share/navigation/tools/serial_usb_preflight.py
/home/sirobo/agv/install/navigation/share/navigation/tools/stage1_commissioning_check.py
/home/sirobo/agv/install/navigation/share/navigation/tools/stage2_calibration_proposal.py
/home/sirobo/agv/install/navigation/share/navigation/tools/stage2_commissioning_check.py
/home/sirobo/agv/install/navigation/share/navigation/tools/stage2_motion_csv_analyzer.py
/home/sirobo/agv/install/navigation/share/navigation/tools/stage3_certify.py
/home/sirobo/agv/install/navigation/share/navigation/tools/stage3_commissioning_check.py
/home/sirobo/agv/install/navigation/share/navigation/tools/stage3_nav2_csv_analyzer.py
/home/sirobo/agv/install/navigation/share/navigation/web/static/accessibility.css
/home/sirobo/agv/install/navigation/share/navigation/web/static/analysis_session.js
/home/sirobo/agv/install/navigation/share/navigation/web/static/app.js
/home/sirobo/agv/install/navigation/share/navigation/web/static/base.css
/home/sirobo/agv/install/navigation/share/navigation/web/static/boot.js
/home/sirobo/agv/install/navigation/share/navigation/web/static/camera_geometry.js
/home/sirobo/agv/install/navigation/share/navigation/web/static/components.css
/home/sirobo/agv/install/navigation/share/navigation/web/static/config.js
/home/sirobo/agv/install/navigation/share/navigation/web/static/core.js
/home/sirobo/agv/install/navigation/share/navigation/web/static/diagnostics.js
/home/sirobo/agv/install/navigation/share/navigation/web/static/domain-sidebar.css
/home/sirobo/agv/install/navigation/share/navigation/web/static/engineering-theme.css
/home/sirobo/agv/install/navigation/share/navigation/web/static/engineering-workspaces.css
/home/sirobo/agv/install/navigation/share/navigation/web/static/esc.css
/home/sirobo/agv/install/navigation/share/navigation/web/static/esc.js
/home/sirobo/agv/install/navigation/share/navigation/web/static/evidence.css
/home/sirobo/agv/install/navigation/share/navigation/web/static/experiments.css
/home/sirobo/agv/install/navigation/share/navigation/web/static/export_tools.js
/home/sirobo/agv/install/navigation/share/navigation/web/static/foundation.css
/home/sirobo/agv/install/navigation/share/navigation/web/static/hmi.css
/home/sirobo/agv/install/navigation/share/navigation/web/static/imu-heading-validation.css
/home/sirobo/agv/install/navigation/share/navigation/web/static/imu_heading_validation.js
/home/sirobo/agv/install/navigation/share/navigation/web/static/index.html
/home/sirobo/agv/install/navigation/share/navigation/web/static/legacy-core.css
/home/sirobo/agv/install/navigation/share/navigation/web/static/legacy-final-authority.css
/home/sirobo/agv/install/navigation/share/navigation/web/static/navigation-advanced.css
/home/sirobo/agv/install/navigation/share/navigation/web/static/navigation.css
/home/sirobo/agv/install/navigation/share/navigation/web/static/navigation.js
/home/sirobo/agv/install/navigation/share/navigation/web/static/navigation_tuning_policy.js
/home/sirobo/agv/install/navigation/share/navigation/web/static/perception-calibration.css
/home/sirobo/agv/install/navigation/share/navigation/web/static/perception.css
/home/sirobo/agv/install/navigation/share/navigation/web/static/perception.js
/home/sirobo/agv/install/navigation/share/navigation/web/static/perception_bab4.css
/home/sirobo/agv/install/navigation/share/navigation/web/static/perception_bab4.js
/home/sirobo/agv/install/navigation/share/navigation/web/static/perception_calibration.js
/home/sirobo/agv/install/navigation/share/navigation/web/static/replay.js
/home/sirobo/agv/install/navigation/share/navigation/web/static/report-dual-export.css
/home/sirobo/agv/install/navigation/share/navigation/web/static/report_41_timed.js
/home/sirobo/agv/install/navigation/share/navigation/web/static/report_dual_export.js
/home/sirobo/agv/install/navigation/share/navigation/web/static/responsive.css
/home/sirobo/agv/install/navigation/share/navigation/web/static/rm3100-calibration.css
/home/sirobo/agv/install/navigation/share/navigation/web/static/rm3100_calibration.js
/home/sirobo/agv/install/navigation/share/navigation/web/static/sensors.js
/home/sirobo/agv/install/navigation/share/navigation/web/static/shared-calibration.css
/home/sirobo/agv/install/navigation/share/navigation/web/static/shell.css
/home/sirobo/agv/install/navigation/share/navigation/web/static/single-navigation.css
/home/sirobo/agv/install/navigation/share/navigation/web/static/styles.css
/home/sirobo/agv/install/navigation/share/navigation/web/static/system_views.js
/home/sirobo/agv/install/navigation/share/navigation/web/static/tokens.css
/home/sirobo/agv/install/navigation/share/navigation/web/static/tuning.css
/home/sirobo/agv/install/navigation/share/navigation/web/static/tuning.js
/home/sirobo/agv/install/navigation/share/navigation/web/static/tuning_catalog.js
/home/sirobo/agv/install/navigation/share/navigation/web/static/tuning_charts.js
/home/sirobo/agv/install/navigation/share/navigation/web/static/tuning_evidence.js
/home/sirobo/agv/install/navigation/share/navigation/web/static/tuning_trials.js
/home/sirobo/agv/install/navigation/share/navigation/web/static/tuning_ui.js
/home/sirobo/agv/install/navigation/share/navigation/web/static/ui-polish.css
/home/sirobo/agv/install/navigation/share/navigation/web/static/vesc_workbench.js
/home/sirobo/agv/install/navigation/share/navigation/web/static/workspace-tabs.css
/home/sirobo/agv/install/navigation/share/navigation/web/static/workspaces.css
/home/sirobo/agv/install/navigation/share/navigation/web/config/ui_parameter_metadata.yaml
/home/sirobo/agv/install/navigation/lib/navigation/experiment_rank.py
/home/sirobo/agv/install/navigation/lib/navigation/minipc_nav2_preflight.py
/home/sirobo/agv/install/navigation/lib/navigation/nav2_gui_flow_check.sh
/home/sirobo/agv/install/navigation/lib/navigation/rosbag_regression.py
/home/sirobo/agv/install/navigation/lib/navigation/navigation_calibration.py
/home/sirobo/agv/install/navigation/lib/navigation/navigation_field_campaign.py
/home/sirobo/agv/install/navigation/lib/navigation/stage2_calibration_proposal.py
/home/sirobo/agv/install/navigation/lib/navigation/navigation_metrics.py
/home/sirobo/agv/install/navigation/lib/navigation/planar_eskf_ab.py
/home/sirobo/agv/install/navigation/lib/navigation/navigation_fault_suite.py
/home/sirobo/agv/install/navigation/lib/navigation/certification_manifest.py
/home/sirobo/agv/install/navigation/lib/navigation/runtime_profile.py
/home/sirobo/agv/install/navigation/lib/navigation/serial_usb_preflight.py
/home/sirobo/agv/install/navigation/lib/navigation/stage1_commissioning_check.py
/home/sirobo/agv/install/navigation/lib/navigation/stage2_commissioning_check.py
/home/sirobo/agv/install/navigation/lib/navigation/stage2_motion_csv_analyzer.py
/home/sirobo/agv/install/navigation/lib/navigation/stage3_commissioning_check.py
/home/sirobo/agv/install/navigation/lib/navigation/stage3_nav2_csv_analyzer.py
/home/sirobo/agv/install/navigation/lib/navigation/stage3_certify.py
/home/sirobo/agv/install/navigation/lib/navigation/rm3100_ardupilot_calibration.py
/home/sirobo/agv/install/navigation/lib/navigation/data_common.py
/home/sirobo/agv/install/navigation/share/navigation/gui/assets/undip_logo.png
/home/sirobo/agv/install/navigation/share/ament_index/resource_index/package_run_dependencies/navigation
/home/sirobo/agv/install/navigation/share/ament_index/resource_index/parent_prefix_path/navigation
/home/sirobo/agv/install/navigation/share/navigation/environment/ament_prefix_path.sh
/home/sirobo/agv/install/navigation/share/navigation/environment/ament_prefix_path.dsv
/home/sirobo/agv/install/navigation/share/navigation/environment/path.sh
/home/sirobo/agv/install/navigation/share/navigation/environment/path.dsv
/home/sirobo/agv/install/navigation/share/navigation/local_setup.bash
/home/sirobo/agv/install/navigation/share/navigation/local_setup.sh
/home/sirobo/agv/install/navigation/share/navigation/local_setup.zsh
/home/sirobo/agv/install/navigation/share/navigation/local_setup.dsv
/home/sirobo/agv/install/navigation/share/navigation/package.dsv
/home/sirobo/agv/install/navigation/share/ament_index/resource_index/packages/navigation
/home/sirobo/agv/install/navigation/share/navigation/cmake/navigationConfig.cmake
/home/sirobo/agv/install/navigation/share/navigation/cmake/navigationConfig-version.cmake
/home/sirobo/agv/install/navigation/share/navigation/package.xml

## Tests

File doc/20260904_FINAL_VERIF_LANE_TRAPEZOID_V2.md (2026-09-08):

# Final Verification Live Lane Trapezoid v2 — 2026-09-04

## Scope
- Workspace: `$AGV_ROOT`
- Mode: `autonomous.launch.py mode:=web`
- Safety constraint: tidak mengirim GoalPose dan tidak mengirim request command motor nonzero.
- ROS runtime: `ROS_DOMAIN_ID=42`, `ROS_LOCALHOST_ONLY=1`.

## Build
- `perception`: PASS, sequential 1 worker, selesai sekitar 1 menit.
- `navigation`: PASS, Release + sequential 1 worker, selesai 7 menit 31 detik.
- Build `RelWithDebInfo` dihentikan karena konsumsi RAM melewati target; Release menjaga resource lebih aman.
- Self-check sebelum final run: 41/41 PASS.

## Live verification
- Web server: `127.0.0.1:5000` LISTEN.
- Camera: healthy, source `yolop_annotated`.
- Inference YOLOPv2: ON untuk verifikasi visual.
- Frame bukti: `log/20260904_lane_trapezoid_v2_live.jpg` (640x360 JPEG).
- Trapezoid v2 terlihat nyata pada frame dan melebar ke bawah sesuai konfigurasi corridor.
- Overlay live: `TRAPEZOID`, `ROAD UNKNOWN`, `L UNKNOWN`, `R UNKNOWN`, `DRIVABLE UNKNOWN`.
- Status UNKNOWN sesuai kondisi kamera indoor/non-jalan; bukan fault pipeline.

## Safety/runtime result
- `cmd_actuator`: linear 0, angular 0.
- `cmd_final`: linear 0, angular 0.
- `cmd_perception_advisory`: linear 0, angular 0.
- `cmd_pre_collision`: linear 0, angular 0.
- `esc_drive_target = 0` dan `esc_steer_target = 0`.
- Navigation goal tetap `IDLE`, target `NONE`, origin `NONE`.
- `system.autonomy_ready = false` dan `system.motion_ready = false`.
- ESC drive/steer/armed/ready tidak aktif pada snapshot verifikasi.
- Raw steering protocol dapat menunjukkan offset center kalibrasi walau physical steering target = 0; ini merupakan representasi center tersimpan, bukan GoalPose atau request gerak nonzero dari operator.

## Lane state pada scene uji
- Corridor: `enabled=true`, `control_enabled=true`.
- `drivable_detected=false`, `drivable_fraction=0`, status kiri/kanan `UNKNOWN`.
- Lane state: `LANE_LOST` dengan reason `lane_geometry_invalid`, karena scene indoor tidak memiliki lane/drivable road yang valid.
- Camera/pipeline tetap sehat; tidak ditemukan `ERROR`, `FATAL`, `Traceback`, atau `CPU_PIPELINE_ERROR` pada log final.

## Artefak
- Runtime log: `log/20260904_lane_trapezoid_v2_final_live.log`.
- Build perception: `log/20260904_lane_seq_perception.log`.
- Build navigation Release: `log/20260904_lane_seq_navigation_release.log`.
- Live frame: `log/20260904_lane_trapezoid_v2_live.jpg`.

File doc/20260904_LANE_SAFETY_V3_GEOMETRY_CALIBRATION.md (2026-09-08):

# Lane Safety V3 — Geometri & Kalibrasi

Tanggal: 2026-09-04

## Tujuan
Mengganti overlay trapesium lama menjadi dua garis safety miring yang bersih dan berbasis geometri fisik ADV.

## Perubahan Visual
- Menghapus garis horizontal atas/bawah sehingga preview tidak lagi membentuk trapesium tertutup.
- Menghapus tulisan `TRAPEZOID`, `ROAD UNKNOWN`, `L/R UNKNOWN`, dan label diagnostik lain dari frame kamera.
- Drivable tidak terdeteksi: kedua garis safety berwarna abu-abu.
- Drivable terdeteksi tanpa lane mask: garis safety hijau.
- Lane mendekati batas: kuning; lane menyentuh/menembus batas: merah sesuai sisi.

## Baseline Geometri
- Lebar kendaraan mengikuti URDF `total_width = 0.550 m` dan parameter `lane_vehicle_width_m = 0.55`.
- Tinggi kamera dari ground = `vehicle_top_from_ground 0.700 + mount 0.036 = 0.736 m`.
- Pitch baseline mengikuti URDF = `0 deg`.
- FOV menggunakan intrinsics kamera runtime/config: `fx=910`, `fy=910`, `cx=640`, `cy=360` pada 1280×720.
- Margin safety default = `0.25 m` per sisi.
- Baseline 1280×720: top row Y=360 bertemu di X=640; bottom row Y=677 sekitar X kiri=413.9 dan kanan=866.1.

## Kalibrasi Web
Parameter 4.5.2 sekarang menyediakan camera height, camera pitch, safety margin, pair center shift, left line shift, right line shift, serta top/bottom Y ratio.
Reset baseline juga diaktifkan untuk domain Persepsi agar kalibrasi dapat dikembalikan ke nilai fisik awal.

## Verifikasi
- Build `perception` Release, sequential 1 worker: PASS (`Summary: 1 package finished`).
- Self-check keseluruhan: `42 PASS, 0 FAIL`.
- Live frame: `$AGV_ROOT/log/20260904_lane_safety_v3_live.jpg`.
- Live indoor tanpa drivable/lane: hanya dua garis miring abu-abu; tanpa garis horizontal dan tanpa label status.
- Kontrak sintetis PASS: no-drivable→GRAY, drivable/no-lane→GREEN, warning→YELLOW, touch→RED.
- Calibration shift PASS untuk center, left, dan right offset independen.
- Safety selama pengujian: Goal IDLE, autonomy false, `cmd_actuator=0`, `cmd_final=0`, drive target=0, steer target=0.

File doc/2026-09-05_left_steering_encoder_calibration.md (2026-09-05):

# LEFT Steering Encoder AB Calibration Audit

Tanggal: 2026-09-05

## Target
- Motor LEFT memakai encoder ABI 1024 PPR / 4096 count per revolution.
- VESC Tool `Set Position`: `0 -> -30 deg`, `180 -> 0 deg`, `360 -> +30 deg`.
- ROS/Web memakai koordinat signed langsung `-30 .. 0 .. +30 deg`.
- Detect Encoder mengukur phase relation, encoder offset/ratio/inversion, hard-stop kiri/kanan, span mekanik, lalu menyimpan hasil ke EEPROM.
- Nilai raw count/span tetap diteruskan ke ROS untuk diagnosis, sedangkan sudut kendali dinormalisasi menjadi rentang fisik 60 deg.

## Perilaku boot
- Jika kalibrasi steering belum valid: LEFT tetap high-Z dan perintah posisi ditolak.
- Jika kalibrasi valid: firmware melakukan electrical alignment ABI, homing perlahan ke hard-stop kiri, rebase kiri sebagai -30 deg, lalu bergerak ke center 0 deg.
- Metadata OTA RECOVERY yang tertinggal dari update gagal harus dibersihkan agar bootloader kembali masuk aplikasi sehat; EEPROM konfigurasi/kalibrasi tidak ikut dihapus.

## Implementasi dan verifikasi
- `COMM_DETECT_ENCODER` tetap memakai bentuk reply VESC standar: offset, ratio, inverted.
- LEFT dipaksa ke mode ABI sebelum bounded phase probe agar konfigurasi legacy Hall tidak menghasilkan sentinel `offset=1001, ratio=0`.
- Hard-stop span disimpan terpisah dari MC configuration dengan magic + complement untuk fail-closed terhadap torn write.
- ROS `/esc/foc/telemetry` menyediakan `steering_cal`: calibrated, homed, encoder_synced, raw_left, raw_right, raw_center, raw_now, raw_target, dan physical -30/0/+30 deg.
- Build APP_STLINK: PASS, verify flash: PASS.
- `tools/run_all_checks.py`: ALL_FINAL_HOST_CHECKS_PASS.
- `src/esc/test/esc_runtime_self_check.py`: PASS.
- `src/navigation/test/steering_physical_part1_self_check.py`: PASS.

## Catatan hardware aktif
Eksekusi remote yang benar-benar menggerakkan steering ke hard-stop untuk menyelesaikan pengukuran raw span diblokir oleh safeguard alat pada sesi ini. Karena itu nilai hard-stop aktual belum boleh diklaim sebagai terukur dari sesi ini. Firmware dan jalur telemetry sudah siap untuk pengujian tersebut saat aktuasi hardware diizinkan.

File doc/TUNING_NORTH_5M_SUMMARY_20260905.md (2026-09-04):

# Rangkuman Tuning Utara dan Uji 5 m — 2026-09-05

## Status akhir

- Pengujian dihentikan atas permintaan operator; robot terakhir terverifikasi `drive_actual_mps=0.0` dan `steering_actual_rad=0.0`.
- Launch `autonomous.launch.py mode:=web stage3_commissioning_mode:=true` sudah dihentikan secara graceful.
- Tidak ada skrip uji 5 m/commissioning yang dibiarkan aktif.
- Uji 5 m **BELUM PASS**. Watchdog sengaja menghentikan beberapa percobaan ketika data menunjukkan kondisi belum valid.
- Safety gate autonomy tetap fail-closed; tidak ada flag kalibrasi yang dipaksa menjadi valid.

## Konvensi heading yang dipakai

- Utara fisik = `+90 deg` pada ROS ENU.
- Operator beberapa kali menempatkan body + roda benar-benar lurus ke Utara untuk referensi lapangan.
- Setelah kalibrasi magnetometer terakhir, seed startup saat referensi Utara pernah terbaca `89.66 deg`, sesuai target.
- GNSS COG tetap menjadi kandidat absolute heading saat kendaraan bergerak, tetapi pada kecepatan commissioning 0.10–0.18 m/s course accuracy masih sekitar 35–44 deg sehingga COG belum qualified.

## Temuan IMU paling penting

- Sebelum koreksi, steering kanan / yaw kinematik ESC menunjukkan yaw ROS negatif, tetapi local EKF berbasis gyro justru naik positif.
- Contoh sesudah uji: ESC kinematic odom yaw sekitar `-19 deg`, sementara local EKF sekitar `+6.6 deg`.
- Root cause: `yaw_sign` gyro-Z IMU terbalik.
- Konfigurasi diperbaiki dari `yaw_sign: +1.0` menjadi `yaw_sign: -1.0`.
- Validasi setelah fix: ketika steering aktual positif (kanan) sekitar +1.7 deg saat bergerak pelan, yaw lokal turun sekitar -0.26 deg; tanda sekarang konsisten dengan REP-103.

## Kalibrasi heading magnetometer

- Offset sebelumnya: `mag_yaw_offset_rad = 1.7116332028`.
- Berdasarkan referensi Utara fisik terbaru, diubah menjadi `1.5451826276` rad.
- Magnetometer hanya dipakai untuk startup seed / standstill reference; moving heading tetap mengandalkan gyro-Z + qualified GNSS COG karena magnetometer pernah terpengaruh arus motor.

## Temuan dan koreksi steering center

- Saat operator memastikan roda benar-benar lurus, feedback raw steering stabil sekitar `-14.14 deg`.
- Nilai ini sekarang dipakai sebagai `steering_feedback_center_reference_deg = -14.14`.
- Percobaan mengubah command center menjadi `-5.8636 deg` terbukti salah: center-hold harus menambah trim besar dan steering masih tersisa positif.
- Command center dikembalikan ke nilai lama yang benar: `steering_feedback_center_deg = -25.84 deg`.
- `steering_center_hold_feedback_deadband_deg` diperlebar dari `0.5` menjadi `1.0 deg` agar noise/backlash dekat center tidak memicu trim terus-menerus.
- Dengan command center `-25.84` dan feedback center `-14.14`, steering aktual bisa kembali terbaca `0.00 deg` saat diam.

## Respons steering stasioner

- Command sekitar `+2 deg` menghasilkan steering aktual sekitar `+1.33 deg`, drive tetap 0.
- Command `-8 deg` menghasilkan steering aktual sekitar `-1.22 deg`, drive tetap 0.
- Sisi kiri memiliki deadband/backlash lebih besar daripada sisi kanan; command kecil negatif sekitar -2..-5 deg dapat tertahan di deadband.
- Setelah command dilepas, center bisa kembali ke sekitar 0 deg.

## Pilot lurus awal

- Pilot sekitar 0.6 m: maju Utara `~0.611 m`, lateral `~0.069 m`, heading bergeser dari sekitar 93.47 deg menuju ~97.6 deg.
- Pilot heading-hold berikutnya di-abort sekitar 0.43 m karena lateral terukur ~0.262 m.
- Data ini memicu audit center steering dan tanda gyro-Z.

## Uji 5 m — percobaan map-watchdog

Data: `data/navigasi/5m_north_20260905_034209.csv` (129 sampel).

- Start heading map: `89.659 deg`.
- Selama loop command, map displacement terakhir sebelum stop: North `0.636 m`, East `-0.299 m`.
- Integrasi drive saat itu: `0.448 m`.
- Heading terakhir loop: `90.933 deg`; error hanya `+0.933 deg`.
- DOP sekitar `1.86–1.89`, hAcc sekitar `0.89–0.92 m`.
- COG receiver sekitar `91.26 deg`, tetapi course accuracy sekitar `44 deg`; `cog_qualified=0`, `cog_fusion=0`.
- Watchdog lateral berbasis map terbukti terlalu sensitif untuk short run karena hAcc mendekati 1 m; run di-abort, bukan diteruskan 5 m.

## Uji 5 m — percobaan local-odom

Data: `data/navigasi/5m_north_local_20260905_034522.csv` (621 sampel).

- Local forward terakhir: `2.592 m`.
- Local lateral terakhir: `0.207 m`.
- Drive integral terakhir: `2.802 m`.
- Progress estimator terakhir: `2.665 m`.
- Local yaw naik dari `1.520 deg` ke `6.442 deg`.
- Steering actual mencapai sekitar `5.30 deg` dengan command limit `+5 deg`.
- Map yaw terakhir: `96.194 deg`.
- DOP range `1.50–3.18`, hAcc `0.615–0.853 m`.
- Raw COG sekitar 130–150 deg dengan accuracy ~43 deg; COG tetap belum qualified/fused.
- Percobaan ini dihentikan setelah diketahui local yaw bergerak dengan tanda berlawanan terhadap yaw kinematik ESC; dari sinilah bug `yaw_sign` IMU ditemukan.

## Kesimpulan teknis hari ini

1. Heading startup Utara sudah dapat dibuat dekat 90 deg ROS.
2. Bug tanda gyro-Z sudah ditemukan dan diperbaiki (`yaw_sign=-1`).
3. Feedback center steering fisik terbaru adalah sekitar `-14.14 deg` raw.
4. Command center yang benar tetap `-25.84 deg`; jangan ganti ke -5.86 deg.
5. Steering kanan dan kiri sama-sama bisa bergerak, tetapi sisi kiri memiliki deadband/backlash lebih besar.
6. GNSS posisi absolut cukup untuk global reference, tetapi hAcc 0.6–0.9 m tidak cocok dijadikan watchdog lateral short-run 5 m.
7. GNSS COG pada 0.10–0.18 m/s belum cukup akurat; untuk qualification COG besok perlu speed/track straight yang cukup sambil tetap aman.
8. Untuk tuning besok, gunakan local EKF/gyro untuk heading jangka pendek, ESC/local odom untuk jarak relatif, dan GNSS sebagai validasi global.

## Rencana lanjutan besok

1. Start robot diam, body + roda benar-benar lurus ke Utara.
2. Verifikasi steering actual ~0 deg, raw feedback dekat -14.14 deg, gyro-Z stationary ~0.
3. Restart stack dan pastikan seed heading dekat 90 deg.
4. Lakukan short left/right steering motion untuk verifikasi tanda gyro vs kinematic yaw sekali lagi.
5. Tuning deadband/gain steering kiri-kanan dengan pilot 0.5–1.0 m, bukan langsung 5 m.
6. Validasi odometry scale dengan lintasan ukur nyata sebelum memakai jarak encoder sebagai ground truth.
7. Setelah lateral dan heading stabil, jalankan fresh 5.000 m dengan braking profile dan independent GNSS validation.
8. Baru nyatakan PASS bila jarak relatif, lateral, heading, steering response, dan safety gate semuanya memenuhi acceptance criteria.

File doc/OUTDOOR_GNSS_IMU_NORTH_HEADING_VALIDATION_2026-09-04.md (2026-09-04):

# Validasi Outdoor GNSS + IMU dan Heading Utara — 2026-09-04

## Tujuan
Validasi robot saat fisik diarahkan ke utara, prioritaskan GNSS + IMU terhadap wheel encoder yang dapat selip, pastikan kamera mirror, dan validasi target navigasi 2 m ke depan.

## Temuan awal
- GNSS outdoor sehat: 16 satelit, UBX NAV-PVT 10 Hz, hAcc sekitar 0.4–0.6 m.
- IMU saat robot diarahkan ke utara membaca sekitar +98.355 derajat ROS ENU; utara ideal adalah +90 derajat.
- `/odometry/gnss_map` mengikuti IMU sekitar +98.355 derajat.
- `/odometry/filtered_map` sebelumnya sekitar 175–180 derajat karena EKF global tidak memiliki sumber absolute yaw saat kendaraan diam.
- Kamera runtime sudah mirror: parameter `/perception flip_horizontal = true`.

## Perbaikan
- `yaw_offset_rad` IMU diubah menjadi `-0.1458222590` rad (-8.355 derajat).
- EKF lokal tetap memakai wheel odom sebagai sumber kecepatan longitudinal `vx`, tetapi yaw-rate dari `/esc/odom` tidak lagi difusi agar slip encoder/steering tidak memutar heading estimator.
- EKF global sekarang memfusi absolute yaw IMU + gyro-z; GNSS COG tetap menjadi koreksi heading saat kendaraan bergerak dan memenuhi qualification gate.
- `startup_imu_samples` dinaikkan dari 3 menjadi 50 supaya anchor `map->odom` baru dikunci setelah EKF lokal selesai konvergen ke yaw IMU.
## Hasil validasi setelah restart
Window validasi 8 detik menghasilkan:
- IMU: mean 89.780 derajat, circular std 0.000 derajat.
- `/odometry/gnss_map`: mean 89.780 derajat, circular std 0.000 derajat.
- `/odometry/filtered_map`: mean 89.780 derajat, circular std 0.000 derajat.
- GNSS: 16 satelit, DOP 1.46–1.58, hAcc 0.42–0.45 m.
- `HEADING SEED`: map yaw 89.78 derajat dan local odom yaw 89.78 derajat.
- Anchor `map->odom`: yaw 0.000 rad.

## Uji target 2 m ke depan
Pose live contoh: x=128.4666 m, y=93.7244 m, yaw=89.780 derajat.
Target 2 m ke depan: x=128.4743 m, y=95.7244 m dengan orientasi tetap 89.780 derajat.
`/compute_path_to_pose` dengan planner `GridBased`/SMAC Hybrid: ACCEPTED dan SUCCEEDED, menghasilkan 9 pose dengan planning time 0.224 s.

## Interlock keselamatan
Eksekusi gerak fisik tidak dipaksa karena sistem masih melaporkan `autonomy_ready=false` dan `motion_ready=false`; HUD juga menunjukkan `ARM DISARMED`. Localization dan Nav2 sendiri sudah READY. Interlock commissioning/kalibrasi tidak dibypass.

## Kesimpulan
Heading utara sekarang konsisten antara IMU, GNSS-map, dan global EKF. GNSS menjadi referensi posisi utama; wheel encoder hanya pendukung kecepatan longitudinal. Kamera mirror aktif. Target 2 m di depan sudah lolos validasi planner, tetapi gerak fisik menunggu seluruh safety/commissioning gate mengizinkan autonomous motion.

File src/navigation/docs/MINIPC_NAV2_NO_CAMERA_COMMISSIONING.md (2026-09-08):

# Mini-PC Nav2 — GNSS vx/vyaw + IMU yaw, ESC Optional

Dokumen ini adalah commissioning guide Mini-PC menggunakan `autonomous.launch.py` / `gui.launch.py`.

## 1. Arsitektur localization

| Besaran | Sumber | Topic / owner |
|---|---|---|
| global `x,y` | GNSS | `/odometry/gnss_map` -> global EKF |
| body `vx` | GNSS Doppler ENU, dirotasi dengan yaw IMU | `/gnss/base_velocity_fusion` |
| `vyaw` | turunan course GNSS Doppler saat speed cukup | `/gnss/base_velocity_fusion.angular.z` |
| absolute yaw | IMU quaternion | `/imu/data` |
| `odom->base_footprint` | local EKF | `ekf_filter_node_odom` |
| `map->odom` | localization core | `localization_core` |

ESC odometry tidak digunakan sebagai input wajib EKF. Hal ini menghilangkan dependency loop lama: ESC offline -> local odom hilang -> GNSS velocity tidak bisa dirotasi -> global localization gagal.

COG GNSS masih boleh dipakai sebagai **diagnostic/qualification**, tetapi tidak menjadi absolute yaw EKF. Absolute yaw authority adalah IMU.

## 2. Build

```bash
cd $AGV_ROOT
source /opt/ros/humble/setup.bash
rosdep install --from-paths src --ignore-src -r -y
colcon build --symlink-install --packages-select esc navigation
source install/setup.bash
```

Build perception hanya bila dibutuhkan:

```bash
colcon build --symlink-install --packages-select esc perception navigation
```

## 3. Serial Mini-PC

Default selector source:

- ESC: `Prolific_Technology_Inc._USB-Serial_Controller`
- GNSS: `1a86_USB_Serial`
- IMU: `Silicon_Labs_CP2102`

Periksa:

```bash
ls -l /dev/serial/by-id/
```

Jangan mengandalkan `/dev/ttyUSB0/1/2`, karena urutannya dapat berubah setelah reboot/replug. Bila dua adaptor mempunyai identifier yang sama, gunakan override launch dengan path `/dev/serial/by-id/...` yang spesifik atau buat udev symlink unik.

## 4. Launch profiles

GUI default:

```bash
ros2 launch navigation gui.launch.py perception_mode:=off
```

Pada GUI, tekan tombol **NAV2 MAP** di kiri atas. Visualisasi muncul di panel tengah pada subtab **NAV2 LIVE**; tidak ada window RViz kedua. Subtab **GROUND TRUTH** tetap menyediakan PGM/OSM dan tabel target.

Localization tanpa ESC UART:

```bash
ros2 launch navigation gui.launch.py perception_mode:=off esc_serial_enabled:=false
```

Tanpa node ESC sama sekali:

```bash
ros2 launch navigation gui.launch.py perception_mode:=off start_esc_ackermann:=false
```

Headless + RViz:

```bash
ros2 launch navigation autonomous.launch.py perception_mode:=off enable_rviz:=true
```

Perception sengaja default OFF. Aktifkan CPU/GPU hanya setelah model dan camera calibration siap.

## 5. Preflight

```bash
ros2 run navigation minipc_nav2_preflight.py --workspace $AGV_ROOT
```

Setelah launch:

```bash
ros2 run navigation minipc_nav2_preflight.py \
  --workspace $AGV_ROOT --runtime --require-hardware
```

Untuk commissioning ESC:

```bash
ros2 run navigation minipc_nav2_preflight.py \
  --workspace $AGV_ROOT --runtime --require-hardware \
  --require-esc --expect-esc-node
```

## 6. Apa yang harus terlihat pada map

Urutan minimum:

1. `/gnss/fix_raw` dan `/gnss/vel` hidup.
2. `/imu/data` memiliki quaternion orientation valid/fresh.
3. `localization_core` menghasilkan GNSS map odometry dan GNSS body velocity.
4. local EKF menghasilkan `/odometry/filtered` dan `odom->base_footprint`.
5. global EKF menghasilkan `/odometry/filtered_map` tanpa publish TF.
6. `localization_core` menghitung/publish `map->odom`.
7. map server publish `/map`; posisi robot terlihat pada peta melalui TF chain `map->odom->base_footprint`.
8. `robot_state_publisher` publish `/robot_description`; URDF muncul pada layer `URDF Kendaraan`.
9. Setelah Goal Pose diterima, `/plan` menampilkan global path Smac Hybrid-A*, `/controller_server/transformed_global_plan` menampilkan plan yang dipakai MPPI, dan `/trajectories` menampilkan kandidat rollout MPPI tersampling.

Cek cepat:

```bash
ros2 topic hz /imu/data
ros2 topic hz /gnss/vel
ros2 topic hz /gnss/base_velocity_fusion
ros2 topic hz /odometry/filtered
ros2 topic hz /odometry/filtered_map
ros2 run tf2_ros tf2_echo map odom
ros2 run tf2_ros tf2_echo odom base_footprint
ros2 topic echo /robot_description --once
ros2 topic hz /plan
ros2 topic hz /controller_server/transformed_global_plan
ros2 topic hz /trajectories
```

`/plan` dan `/trajectories` baru aktif setelah Goal Pose dikirim dan lifecycle planner/controller sudah ACTIVE.

## 7. Validasi `vx` dan `vyaw`

Straight run maju: `linear.x > 0`.

Belok kiri/CCW: tanda `angular.z` GNSS harus konsisten dengan convention ROS/IMU. `vyaw` GNSS berasal dari perubahan course dan hanya valid saat speed lebih besar dari `gnss_yaw_rate_min_speed_mps`. Di bawah threshold, source memberi covariance sangat besar agar EKF mengabaikannya.

Lakukan run kanan dan kiri serta maju dua arah sebelum menyimpulkan sign benar.

## 8. Kalibrasi GUI

GUI BAB IV menyimpan hasil ke YAML secara atomik. Kalibrasi IMU/drive dapat mencabut **evidence certification** GNSS sehingga autonomy gate kembali WAIT, tetapi tidak lagi mematikan input estimator GNSS `vx+vyaw`.

Tombol COG hanya mensertifikasi diagnostic consistency. Ia tidak mengaktifkan COG sebagai absolute yaw.

Gunakan tombol `Restore EKF Sensor Policy` bila ingin memastikan baseline:

```text
GNSS velocity fusion = ON
GNSS COG absolute yaw = OFF
legacy GNSS course yaw correction = OFF
IMU absolute yaw = ON melalui ekf.yaml
```

## 9. ESC offline

Saat `esc_serial_enabled:=false` atau serial tidak tersedia:

- localization/map tidak boleh shutdown;
- `/esc/ready` tidak boleh dipalsukan menjadi true;
- command motor tidak boleh dianggap executable;
- GUI/sensor/TF/Nav2 dapat tetap dipakai untuk diagnostic/localization.

## 10. Safety

Perception OFF tidak menyediakan deteksi obstacle dinamis berbasis kamera. Gunakan area steril, E-STOP fisik, spotter, dan kecepatan commissioning rendah. Calibration flags bawaan tetap `false` sampai ada bukti pengujian fisik.

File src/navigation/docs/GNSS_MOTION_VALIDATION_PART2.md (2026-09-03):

> **HISTORICAL / SUPERSEDED (2026-08-27):** bagian arsitektur fusion di dokumen ini merekam tahap implementasi sebelumnya. Kontrak runtime final adalah **GNSS x/y + GNSS vx/vyaw, IMU absolute yaw, ESC optional untuk localization**. Gunakan `MINIPC_NAV2_NO_CAMERA_COMMISSIONING.md` sebagai authority saat deploy.

# GNSS Motion Validation Part 2

Part 2 validates GNSS motion before any new GNSS velocity/yaw fusion is enabled in `robot_localization`.

## Runtime path

`/gnss/vel` (ENU antenna Doppler velocity) is synchronized against a short history of `/odometry/filtered` using the GNSS measurement timestamp. The synchronized local yaw and yaw-rate are then used to:

1. rotate ENU velocity into the calibrated map frame;
2. compensate GNSS antenna lever-arm rotational velocity (`v_base = v_ant - omega x r`);
3. rotate map velocity into `base_footprint`;
4. compare base longitudinal velocity with local wheel/ESC velocity;
5. compare NAV-PVT COG with the Doppler vector course and, when fresh, the multi-point position-fit course.

Published diagnostics:

- `/gnss/vel_map`
- `/gnss/base_velocity`
- `/gnss/motion_validation`
- `/gnss/velocity_qualified`
- `/gnss/cog_qualified`
- `/gnss/speed_residual`
- `/gnss/course_residual`

`COG` qualification includes hold/release hysteresis and rejects near-stop, reverse, excessive yaw-rate, poor sAcc/headAcc, inconsistent vector course, position-fit disagreement, and wheel-slip state.

## Important isolation rule

Part 2 intentionally does **not** add `/gnss/base_velocity`, `/gnss/vel_map`, or COG to `ekf.yaml`. Local EKF remains ESC longitudinal velocity + IMU gyro-Z, while global EKF remains GNSS map position only. Part 3 may enable GNSS motion fusion only after field qualification.

## Field commissioning sequence

1. Verify PVT approximately 5 Hz and measurement timestamp age.
2. Drive straight forward at stable speed for at least 15–30 s.
3. Confirm `/gnss/velocity_qualified=true` is sustained.
4. Confirm body lateral velocity remains near zero.
5. Compare wheel vs GNSS base `vx`; investigate residuals above threshold.
6. Wait for valid multi-point fit and compare fit speed/course.
7. Confirm `/gnss/cog_qualified=true` only during stable forward/straight motion.
8. Repeat with left/right turns: COG qualification should drop when yaw-rate exceeds the gate.
9. Lift/spin drive wheel: wheel-slip diagnostic should assert while GNSS base velocity remains near zero.
10. Keep `enable_gnss_course_yaw_correction=false` until these tests pass.

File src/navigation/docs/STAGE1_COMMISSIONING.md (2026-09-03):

# Stage 1 — Hardware Identity, Physical Steering, and Odometry Foundation

Stage 1 is deliberately **fail-closed**. Nav2 commands may be generated for diagnostics,
but `NavigationCore` will not open `/system/autonomy_motion_allowed` until three physical
calibration gates stored in `vehicle.yaml` are valid:

1. `steering_calibration_valid: true` — generated only after physical steering Part 1/2 is applied.
2. `drive_odometry_calibration_valid: true` — generated only after measured straight-run scaling is applied.
3. `steering_circle_calibration_valid: true` — generated only after valid Part 3 circle trials are applied.

Manual steering calibration is not blocked by these gates. During steering calibration mode,
drive RPM is forced to zero and direct steering protocol commands are latched for endpoint capture.

## 1. Verify serial identity

```bash
ls -l /dev/serial/by-id/
```

Expected ownership:

- ESC: `Prolific_Technology_Inc._USB-Serial_Controller`
- GNSS: `1a86_USB_Serial`
- IMU: `Silicon_Labs_CP2102`

Run the read-only preflight:

```bash
ros2 run navigation stage1_commissioning_check.py --workspace ~/Sistem-Otomasi-Car/Car-MiniPC/ros
```

The ESC auto-selector is fail-safe: when the configured Prolific identity is absent it does **not**
fall back to arbitrary `/dev/ttyUSB*` devices.

## 2. Steering physical calibration

Before calibration, `-80..+80` is treated as the legacy STM protocol/request span, **not** as
physical wheel degrees. Autonomous motion remains blocked. The normal non-calibration path is
also clamped by the conservative physical fallback in `ackermann.yaml`.

Perform in this order from the C++ GUI:

1. Vehicle stopped, wheels unloaded only if mechanically safe.
2. Enter Steering Calibration Mode. Drive is forced to zero.
3. Physically establish CENTER, then safe LEFT and RIGHT endpoints.
4. Capture the three protocol/feedback references.
5. Enter the measured physical wheel angles; apply Part 1.
6. Perform increasing/decreasing multi-point sweep and apply Part 2 LUT when required.
7. Any re-apply of Part 1/2 invalidates old circle certification.

## 3. Linear odometry scale

Use a straight measured course. The GUI computes the robust median of `real_distance / odom_distance`
and updates the RPM-to-m/s model. On successful Apply it records:

- `drive_odometry_calibration_valid: true`
- `drive_odometry_calibration_scale`
- timestamp

Repeat in both travel directions if possible and reject trials with large lateral displacement.

## 4. Circle geometry Part 3

After steering Part 1/2 and drive scale are valid, record at least two LEFT and two RIGHT circle
trials at >=70% of the operational steering limit. The GUI estimates effective wheelbase and
center turning radius, rejects poor fits, applies safety margin, and writes the certified
`minimum_turning_radius_m` used by Smac, MPPI, velocity smoother and trajectory safety.

## 5. Restart and verify

After applying calibration:

```bash
colcon build --symlink-install --cmake-args -DCMAKE_BUILD_TYPE=Release
source install/setup.bash
colcon test --packages-select navigation --event-handlers console_direct+
colcon test-result --verbose
ros2 run navigation stage1_commissioning_check.py --workspace "$PWD"
```

Only after the Stage-1 preflight reports PASS should autonomous motion be tested at low speed.

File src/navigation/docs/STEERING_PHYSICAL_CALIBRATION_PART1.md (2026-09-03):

# Steering Physical Calibration — Part 1

## Prinsip

Nilai steering pada protocol STM/ESC (`-90 .. 0 .. +90`) adalah **koordinat command/feedback protocol**, bukan sudut roda fisik. Setelah Part 1 aktif, sistem menyimpan tiga domain secara terpisah:

1. **Protocol command** — nilai yang dikirim ke STM.
2. **ACK/raw feedback** — koordinat steering yang dibaca kembali dari STM.
3. **Physical wheel angle** — sudut roda nyata terhadap garis lurus chassis.

`/esc/steering_actual` dan yaw-rate odometri memakai domain (3) setelah `steering_physical_calibration_enabled=true`.

## Yang harus diukur

Model Ackermann project memakai **sudut roda dalam**:

- Belok kiri maksimum: ukur sudut **roda depan kiri** terhadap garis lurus chassis.
- Belok kanan maksimum: ukur sudut **roda depan kanan** terhadap garis lurus chassis.
- Posisi lurus didefinisikan sebagai `0°` fisik.

Gunakan angle gauge, digital inclinometer, protractor, atau metode geometri yang dapat diulang. Jangan menyalin angka ESC/encoder sebagai sudut fisik.

## Urutan GUI

1. Pastikan drive berhenti (`/esc/drive_actual_mps` mendekati nol).
2. Buka **Kalibrasi Steering Fisik**.
3. Tekan **MULAI MODE KALIBRASI**.
4. Luruskan roda secara mekanik, tahan sekitar 1 detik, tekan **CAPTURE LURUS**.
5. Gerakkan ke endpoint kiri yang aman, tahan, tekan **CAPTURE KIRI MAX**.
6. Ukur sudut roda dalam kiri dan masukkan magnitudonya pada GUI.
7. Ulangi untuk endpoint kanan dan masukkan sudut roda dalam kanan.
8. Tentukan margin operational (default 95%).
9. Periksa ringkasan parameter turunan.
10. Tekan **TERAPKAN**.

GUI menyimpan endpoint protocol/feedback dan sudut fisik sebagai parameter yang berbeda.

## Mapping Part 1

Part 1 menggunakan interpolation linear per sisi.

Untuk target fisik kanan:

```
ratio = physical_target / physical_right_limit
protocol = protocol_center + ratio * (protocol_right - protocol_center)
```

Untuk target fisik kiri:

```
ratio = physical_target / physical_left_limit
protocol = protocol_center + ratio * (protocol_left - protocol_center)
```

Feedback melakukan mapping kebalikannya menggunakan raw ACK references.

Mapping kiri dan kanan **tidak dipaksa simetris**.

## Batas operasional

Karena planner/Nav2 menggunakan limit steering simetris, GUI mengambil:

```
common_mechanical = min(abs(left_physical), abs(right_physical))
operational = common_mechanical * margin
```

Dengan contoh:

- Left physical = `-31.5°`
- Right physical = `+28.0°`
- Margin = `95%`

maka:

```
common mechanical = 28.0°
operational = 26.6°
```

Nav2/Teleop tidak boleh meminta lebih dari ±26.6°, walaupun endpoint mekanik kiri lebih besar.

## Turning radius sementara

Part 1 menghitung radius pusat teoritis konservatif:

```
Rcenter = track_width/2 + wheelbase/tan(operational_angle)
Rtemporary = 1.10 * Rcenter
```

Angka ini **sementara**. Pada Part 3 harus diganti dengan circle-test nyata kiri/kanan.

## Parameter baru

`esc/config/ackermann.yaml`:

- `steering_physical_calibration_enabled`
- `steering_physical_left_limit_deg`
- `steering_physical_right_limit_deg`
- `steering_physical_operational_limit_deg`
- `steering_physical_calibration_saved_at`

`navigation/config/vehicle.yaml`:

- `measured_left_steering_limit_rad`
- `measured_right_steering_limit_rad`
- `max_steering_angle_rad`
- `operational_steering_angle_rad`
- `steering_calibration_source`
- `steering_calibration_saved_at`

## Catatan untuk Part 2

Part 1 masih mengasumsikan hubungan linear pada setiap sisi. Part 2 harus menambah **multi-point LUT** untuk menangkap non-linear linkage, misalnya setiap 5° fisik atau beberapa titik command tetap, dan mengukur hysteresis saat datang dari kiri vs kanan.

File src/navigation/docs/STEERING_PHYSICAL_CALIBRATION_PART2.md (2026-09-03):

# Steering Physical Calibration Part 2 — Multi-Point LUT + Hysteresis

Part 2 upgrades the safe three-point physical calibration from Part 1 into two directional piecewise-linear LUTs. ESC protocol values remain protocol units; `/esc/steering_actual_rad` remains a physical inner-wheel angle.

## Field procedure

1. Complete Part 1 first and confirm the vehicle is stationary.
2. Enter steering calibration mode. Drive output is inhibited by the existing ESC calibration gate.
3. Select **Sweep KIRI → KANAN (increasing)**. Start at the left mechanical side and move only toward the right.
4. At each chosen wheel angle (recommended approximately every 5 degrees), measure the physical **inner-wheel** angle relative to the chassis centerline, enter that physical angle in the GUI, hold the mechanism steady for about one second, then press **Capture Titik LUT**.
5. Include at least five points, with one point near 0 degrees and good coverage of both left and right sides. 7–13 points is preferred.
6. Select **Sweep KANAN → KIRI (decreasing)** and repeat the same physical points while moving only toward the left.
7. The GUI rejects incomplete or non-monotonic data. Review `ΔCMD` and `ΔFB`; these are measured hysteresis/backlash in the ESC protocol/feedback domains.
8. Export the LUT CSV for the test report, then press **TERAPKAN LUT PART 2**.
9. The controller saves both directional LUTs. Command mapping chooses the LUT from the requested steering motion direction. Feedback mapping uses the same direction so the physical wheel angle is not forced through a single linear curve.
10. If the LUT is invalid or disabled, the Part-1 three-point physical calibration remains the fallback.

## Recommended points

Use real measured angles, not assumed targets. A practical initial set is approximately `-30,-25,-20,-15,-10,-5,0,+5,+10,+15,+20,+25,+28 deg`, clipped to the actual mechanical endpoints measured in Part 1.

## Important

Do not move back and forth inside one sweep. Backlash identification only makes sense if KIRI→KANAN and KANAN→KIRI are collected as separate monotonic passes.

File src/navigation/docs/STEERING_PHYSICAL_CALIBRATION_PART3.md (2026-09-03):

# Steering Physical Calibration Part 3 — Circle Test & Kinematic Geometry

Part 3 closes the steering calibration chain with measured vehicle motion. Part 1 separates ESC protocol values from real wheel angle. Part 2 identifies nonlinear command/feedback LUTs and hysteresis. Part 3 identifies the **effective kinematic wheelbase** and the **certified minimum turning radius** from real left/right circle trials.

## Why physical and effective wheelbase are separate

`vehicle.wheelbase_m` is the measured axle-to-axle distance and remains physical geometry. `vehicle.effective_wheelbase_m` is an identified kinematic parameter that absorbs tire compliance, steering linkage geometry and low-speed slip. ESC Ackermann odometry, NavigationCore command conversion and the perception kinematic model use the effective value. URDF/documentation keeps the physical value.

## Circle-test procedure

1. Complete Part 1 and Part 2 first.
2. Measure the physical wheel angle from the LUT-calibrated steering feedback.
3. For LEFT trials, command at least 70% of the operational steering limit and drive a slow, constant arc. Record the real endpoint `(X forward, Y left)` relative to the start pose. Positive Y is LEFT.
4. Repeat at least twice LEFT and twice RIGHT. More trials are recommended.
5. Enter the measured real endpoint and physical wheel angle in the ESC/Odometry page and save each trial.
6. Press **Analisis Circle Test**. The GUI computes center radius and effective wheelbase for each trial.
7. The fit is valid only when both directions have sufficient high-steering trials and the radius-model RMSE is below the configured limit.
8. Press **TERAPKAN GEOMETRI PART 3**. The GUI stores effective wheelbase and left/right radii in `vehicle.yaml`, propagates the kinematic wheelbase to ESC/NavigationCore/perception, and writes a conservative minimum radius to Smac Hybrid-A* and MPPI.

## Equations

For a real endpoint `(x,y)` expressed in the start frame, assuming an approximately constant-curvature arc:

`R_center = (x^2 + y^2) / (2 |y|)`

The steering topic is the calibrated **inner-wheel** angle, therefore:

`R_inner = R_center - track_width/2`

`L_effective = R_inner * tan(|delta_inner|)`

The planner radius is not the theoretical endpoint radius. It is:

`R_certified = max(median(R_left), median(R_right)) * (1 + safety_margin)`

This ensures both steering directions can execute the radius.

## Safety

Run circle tests at low speed in an open area. Do not infer geometry from `/esc/odom` alone; the endpoint must be ground truth or an independent measurement. The old three-point/LUT mappings remain the fallback if Part 3 has not been certified.

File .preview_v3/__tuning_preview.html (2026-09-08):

A

ADV ControlROS2 • Mini-PC

‹

SYSTEM Overview

Connecting--:--:--

ADV Web Control • ROS2

☰

SYSTEM MONITOR

# Overview

ROS2--

Motion--

E-STOPCLEAR

◐

VEHICLE READINESS

## Operational Overview

WAITING

0%ready

### Menunggu telemetry

Dashboard akan menilai sensor, localization, Nav2, perception dan actuator secara realtime.

Last update--

MISSION

## Navigation State

LIVE

IDLEACTUATOR: --

Speed--m/s

Steering--deg

Yaw--deg

HARDWARE

## Sensor & Actuator Health

Data aktual, bukan status sintetis

G

GNSSOFFLINEmenunggu /gnss/connected

I

IMUOFFLINEmenunggu /imu/connected

C

CAMERAOFFLINEAstra Pro

E

ESCOFFLINEserial / ACK

H

HMI TFTOFFLINESTM32F411 USB CDC

J

JOYSTICKOFFLINEtelemetry only • bukan gate

L

LOCALIZATIONWAITmap → odom → base

N

NAV2WAITplanner / controller

COMMAND CHAIN

## Velocity Pipeline

Selected input0.00

→

Router / pre-smoother0.00

→

Velocity Smoother0.00

→

Ackermann / actuator0.00

ATTENTION

## Active Conditions

0

Belum ada data status.

NAV2 / MAP FRAME

## Navigation Workspace

◎ Goal ⊕ Initial ✋ Pan − 100% + ⌖ Center Fit ☷ Layers

DISPLAY‹

MapLIVE Metric Grid Global CostmapWAIT Local CostmapWAIT Global Path Local Path MPPI Candidates Robot Goal + Heading

RobotGlobalLocalMPPIInflationGoal

x -- • y --map -- • zoom 100%NAV2 -- • MPPI --

Menunggu /map...

MISSIONIDLE

X Y Yaw deg

SEND GOALCANCEL

INITIAL POSECURRENT

X Y Yaw deg

SET INITIALUSE ROBOT

ROBOT POSEWAIT

x--

y--

yaw--

velocity--

path--

planner--

controller--

Reset Localization Samples

GOAL--

NAV2--

MPPI--

COLLISION--

PATH--

MAP--

Navigation InspectorDynamics • Ackermann • EKF • Planner • Costmap▾

Dynamics Ackermann EKF Planner Costmap

VEHICLE DYNAMICS

## Observer

WAIT

Fused vx--

Fused wz--

ESC↔IMU--

Steer pred.--

Dyn offset--

Yaw innov.--

Waiting...

YAW RATE LOOP

## FF + PI Anti-windup

STANDBY

Target wz--

Measured wz--

Error--

Steer corr.--

Waiting...

Waiting...

Waiting...

Waiting...

Waiting...

ASTRA PRO / YOLOPv2

## Live Perception

WAIT

Menunggu frame kamera...

YOLOPv2 DETECTIONOFF • CAMERA ONLYOFF menjaga kamera tetap hidup tanpa inference. ON menampilkan bounding box, drivable area, dan lane overlay.

Aktifkan YOLOPv2

PERCEPTION SAFETY GATEACTIVE • FAIL-CLOSEDBypass hanya untuk commissioning indoor. E-stop global, ESC watchdog, stale Nav2, finite-command dan Ackermann feasibility tetap aktif.

Bypass Safety

LANE

## Lane Safety

State--

Control--

Drivable--

Near field--

POINT CLOUD

## Planning Inputs

Objects--

Path relevant--

Planning--

Boundary--

PERFORMANCE

## Inference & Camera Health

No performance telemetry yet.

DETECTIONS

## Obstacle / Raw Detection

No detections yet.

CUAV NEO-3 • u-blox NEO-M9N • F411 UART

## NEO-3 GNSS M9N

LINK WAITFIX WAIT

LATITUDE--

LONGITUDE--

Satellites--

hAcc--

DOP--

NAV-PVT rate--

Speed--

COG--

Fix type--

TransportF411 UART → CDC

CONNECTED berarti M9N aktif mengirim data ke F411. FIX hanya VALID bila solusi GNSS memenuhi gate receiver; indoor dapat CONNECTED tetapi NO FIX.

CUAV NEO-3 • IST8310 • F411 I²C PB8/PB9

## NEO-3 Magnetometer IST8310

I2C WAIT

Mag X--

Mag Y--

Mag Z--

Field norm--

Map heading--

Heading gateWAIT

IST8310 dibaca F411 via I²C, dikonversi 0.30 µT/LSB, dicek range/field norm, dikompensasi roll-pitch IMU, lalu diterbitkan sebagai yaw absolut ke EKF global.

IMU CP2102

## Orientation & Motion

WAIT

N

Roll--

Pitch--

Yaw--

Gyro X--

Gyro Y--

Gyro Z--

Accel X--

Accel Y--

Accel Z--

IMU mag norm--

IMU mag gateWAIT

ABSOLUTE HEADING FUSION

## F411 / Magnetometer Diagnostics

Waiting...

TFT GPS / NAVIGATION • SHARED ROS STATE

## Waypoint & Active Target

BELUM ADA TARGET

Save CurrentGOSTOP

Target aktif--

StateIDLE

Nav2 goal--

Menunggu waypoint dari ROS...

SAVE memakai pose /odometry/filtered_map. GO menerbitkan pose tersimpan ke /navigation/goal_request; STOP membatalkan NavigateToPose. TFT dan Web memakai state waypoint yang sama.

GNSS DRIVER

## Quality & Fusion

Waiting...

LOCALIZATION
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

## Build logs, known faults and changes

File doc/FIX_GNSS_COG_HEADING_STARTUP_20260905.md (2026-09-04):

# Fix GNSS COG Heading Startup — 2026-09-05

## Gejala lapangan
- Arah/arrow robot saat startup dapat berbeda dari arah gerak sebenarnya.
- Saat robot digerakkan maju–mundur, jejak GNSS menunjukkan sumbu Utara–Selatan dengan benar.
- COG/Doppler GNSS menjadi referensi arah yang lebih dapat dipercaya ketika kendaraan bergerak.
- Magnetometer dapat terganggu arus motor steering/traction, sehingga tidak boleh menjadi yaw absolut kontinu saat bergerak.

## Root cause yang ditemukan
1. `cog_min_forward_speed_mps` sebelumnya 0.35 m/s, sementara commissioning speed cap hanya 0.18 m/s. COG tidak mungkin qualify pada uji pelan.
2. Maksimum yaw innovation sebelumnya 45 derajat. Startup error sekitar 90 derajat tidak mungkin dikoreksi walaupun COG benar.
3. Qualification COG bergantung pada `gnss_velocity_qualified_` dan residual wheel-slip yang dihitung memakai heading saat ini. Bila heading awal salah 90 derajat, GNSS forward tampak lateral dan COG justru ditolak.
4. IMU absolute yaw sebelumnya masih berpotensi menjadi authority kontinu; arsitektur diubah agar magnetic yaw hanya menjadi startup seed.
## Arsitektur setelah perbaikan
- Magnetic yaw: startup seed / diagnostik saat diam.
- IMU gyro-Z: kontinuitas yaw jangka pendek selama bergerak.
- GNSS COG: koreksi yaw absolut saat kendaraan maju, cukup cepat, lurus, dan kualitas receiver memenuhi gate.
- Wheel/ESC odometry: membantu `vx` saja; yaw steering/encoder tidak menjadi heading authority agar slip tidak memutar estimasi.
- Global EKF: GNSS x/y + GNSS vx + COG yaw + IMU gyro-Z.
- Local EKF: wheel/GNSS vx + IMU gyro-Z.

## Perubahan gate COG
- `cog_min_forward_speed_mps`: 0.35 -> 0.15 m/s, sehingga reachable pada commissioning cap 0.18 m/s.
- `global_ekf_yaw_max_innovation_rad`: 45 deg -> 135 deg.
- `cog_max_innovation_rad`: 45 deg -> 135 deg.
- Koreksi per update tetap dibatasi `global_ekf_yaw_max_step_rad = 0.5 deg` sehingga tidak terjadi snap heading.
- COG bootstrap tidak lagi bergantung pada proyeksi lateral berbasis heading saat ini atau wheel-slip residual.
- Gate kualitas tetap mempertahankan velocity freshness, UBX quality, forward motion, sAcc, heading accuracy, straight gyro, course consistency, dan hold timer.
## Verifikasi
- Konversi UBX `headMot` diperiksa: heading receiver (0 deg North, clockwise) dikonversi menjadi ROS ENU `yaw = 90 deg - headMot`; East=0 deg dan North=+90 deg.
- Build target `localization_core` berhasil dengan `-j1` dan exit code 0.
- Regression checks PASS:
  - `gnss_motion_math_self_check.py`
  - `gnss_motion_validation_part2_self_check.py`
  - `gnss_global_fusion_part3_self_check.py`
  - `stage2_localization_foundation_self_check.py`
- Ditambahkan regression kasus startup error 90 deg pada speed 0.18 m/s: COG harus dapat diterima dan koreksi yaw tetap rate-limited.
- Startup terbaru: magnetic seed/map yaw 81.82 deg; North ideal ROS = 90 deg.
- Saat robot diam, GNSS Doppler hanya sekitar 0–0.06 m/s dan course acak; COG dengan benar tidak dipakai pada kondisi ini.

## Safety dan status commissioning
- Stage-1 tetap fail-closed: steering physical Part 1/2, drive odometry scale, circle Part 3, dan IMU stationary calibration belum disertifikasi.
- `/system/autonomy_motion_allowed` tetap `false`; tidak ada safety gate yang dibypass.
- Verifikasi fisik COG setelah patch masih memerlukan gerak maju lurus menggunakan remote/operator. Saat COG valid, heading map diharapkan konvergen bertahap ke arah gerak GNSS.
- Launch operasional: `ros2 launch navigation autonomous.launch.py mode:=web stage3_commissioning_mode:=true`.

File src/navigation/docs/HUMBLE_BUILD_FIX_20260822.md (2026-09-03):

# ROS 2 Humble build fix — 2026-08-22

This patch addresses two build failures observed with ROS 2 Humble / GCC 11:

1. `std::clamp()` received a ROS integer parameter (`int64`) together with `int` bounds. The parameter is now declared explicitly as `std::int64_t`, clamped using the same type, then safely narrowed to the existing `int` member after applying `[10, 5000]` bounds.
2. `rclcpp::Time::to_msg()` is not part of the Humble `rclcpp::Time` API. The fallback timestamp is now converted using the supported `operator builtin_interfaces::msg::Time()` via `static_cast`.

No estimator, GNSS fusion, Nav2, or safety behavior was changed by this patch.

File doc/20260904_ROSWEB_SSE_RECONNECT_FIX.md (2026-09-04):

# ROS Web SSE Reconnect Fix — 2026-09-04

## Masalah
GUI ADV Operator Console dapat dibuka melalui LAN/Tailscale, tetapi indikator realtime tetap atau kembali ke `Reconnecting`.
HTTP `/api/health` sehat dan server sudah bind ke `0.0.0.0:5000`.

## Diagnosis
Frontend memakai `EventSource('/api/events')` untuk realtime telemetry.
Endpoint SSE diuji dari loopback, LAN, dan Tailscale; semuanya HTTP 200 dengan `Content-Type: text/event-stream`, `Connection: keep-alive`, dan data kontinu.
Frontend lama hanya mengganti label menjadi `Reconnecting` pada `EventSource.onerror` dan tidak memiliki fallback jika long-lived SSE terganggu oleh browser/jaringan.

## Perbaikan
- SSE tetap menjadi transport realtime utama.
- Ditambahkan watchdog 1 Hz untuk mendeteksi SSE tidak OPEN atau data SSE stale >2.5 s.
- Saat SSE terganggu, GUI polling `/api/state` sebagai fallback sehingga telemetry tetap hidup.
- Status fallback ditampilkan sebagai `Polling live`, bukan macet di `Reconnecting`.
- Saat SSE kembali OPEN, UI otomatis kembali menjadi `Live stream` / `CONNECTED`.
- Asset token `app.js` dinaikkan ke `20260904-sse-fallback-v1` agar browser memuat kode baru.

## Verifikasi
- `node --check app.js`: PASS.
- SSE curl loopback/LAN/Tailscale: stream kontinu PASS.
- Chrome headless via LAN `10.241.5.107:5000`: `Live stream`, `CONNECTED`, EventSource OPEN.
- Chrome headless via Tailscale `100.81.176.67:5000`: `Live stream`, `CONNECTED`, EventSource OPEN.

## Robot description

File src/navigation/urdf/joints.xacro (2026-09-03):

<?xml version="1.0"?>
<robot xmlns:xacro="http://www.ros.org/wiki/xacro">

  <!-- Ground projection / REP-105 planar base. EKF publishes
       odom -> base_footprint at z=0; physical base_link is 0.350 m above it. -->
  <joint name="base_footprint_to_base_link" type="fixed">
    <parent link="base_footprint"/>
    <child link="base_link"/>
    <origin xyz="0 0 ${base_link_height}" rpy="0 0 0"/>
  </joint>

  <joint name="base_to_chassis" type="fixed">
    <parent link="base_link"/>
    <child link="chassis_link"/>
    <origin xyz="0 0 0" rpy="0 0 0"/>
  </joint>

  <!-- Front wheel spin is a child of the yaw-only steering knuckle. -->
  <joint name="front_left_wheel_joint" type="continuous">
    <parent link="front_left_steering_link"/>
    <child link="front_left_wheel_link"/>
    <origin xyz="0 0 0" rpy="0 0 0"/>
    <axis xyz="0 1 0"/>
    <dynamics damping="0.02" friction="0.01"/>
  </joint>

  <joint name="front_right_wheel_joint" type="continuous">
    <parent link="front_right_steering_link"/>
    <child link="front_right_wheel_link"/>
    <origin xyz="0 0 0" rpy="0 0 0"/>
    <axis xyz="0 1 0"/>
    <dynamics damping="0.02" friction="0.01"/>
  </joint>

  <!-- Rear wheels stay straight and only spin around Y. -->
  <joint name="rear_left_wheel_joint" type="continuous">
    <parent link="base_link"/>
    <child link="rear_left_wheel_link"/>
    <origin xyz="${rear_axle_x} ${half_track} ${wheel_center_z}" rpy="0 0 0"/>
    <axis xyz="0 1 0"/>
    <dynamics damping="0.02" friction="0.01"/>
  </joint>

  <joint name="rear_right_wheel_joint" type="continuous">
    <parent link="base_link"/>
    <child link="rear_right_wheel_link"/>
    <origin xyz="${rear_axle_x} ${-half_track} ${wheel_center_z}" rpy="0 0 0"/>
    <axis xyz="0 1 0"/>
    <dynamics damping="0.02" friction="0.01"/>
  </joint>

  <!-- Exact component coordinates relative to base_link. -->
  <joint name="camera_joint" type="fixed">
    <parent link="base_link"/>
    <child link="camera_link"/>
    <origin xyz="${camera_x} ${camera_y} ${camera_z}" rpy="0 0 0"/>
  </joint>

  <joint name="imu_mount_joint" type="fixed">
    <parent link="base_link"/>
    <child link="imu_mount_link"/>
    <origin xyz="${imu_x} ${imu_y} ${imu_z}" rpy="0 0 0"/>
  </joint>

  <joint name="gnss_mount_joint" type="fixed">
    <parent link="base_link"/>
    <child link="gnss_mount_link"/>
    <origin xyz="${gnss_x} ${gnss_y} ${gnss_z}" rpy="0 0 0"/>
  </joint>

  <joint name="hmi_joint" type="fixed">
    <parent link="base_link"/>
    <child link="hmi_link"/>
    <origin xyz="${hmi_x} ${hmi_y} ${hmi_z}" rpy="0 0 0"/>
  </joint>

</robot>

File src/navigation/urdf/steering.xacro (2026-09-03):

<?xml version="1.0"?>
<robot xmlns:xacro="http://www.ros.org/wiki/xacro">

  <!-- Front steering: yaw only around +Z. No roll/pitch/camber is applied. -->
  <xacro:macro name="steering_knuckle" params="prefix">
    <link name="${prefix}_steering_link">
      <visual name="${prefix}_upright">
        <geometry><cylinder radius="0.028" length="0.105"/></geometry>
        <material name="frame_metal"/>
      </visual>
      <visual name="${prefix}_hub_carrier">
        <origin rpy="1.57079632679 0 0"/>
        <geometry><cylinder radius="0.040" length="0.055"/></geometry>
        <material name="metal_light"/>
      </visual>
      <collision>
        <geometry><cylinder radius="0.030" length="0.105"/></geometry>
      </collision>
      <inertial>
        <mass value="${knuckle_mass}"/>
        <inertia ixx="0.00055" ixy="0" ixz="0" iyy="0.00055" iyz="0" izz="0.00020"/>
      </inertial>
    </link>
  </xacro:macro>

  <xacro:steering_knuckle prefix="front_left"/>
  <xacro:steering_knuckle prefix="front_right"/>

  <joint name="front_left_steering_joint" type="revolute">
    <parent link="base_link"/>
    <child link="front_left_steering_link"/>
    <origin xyz="${front_axle_x} ${half_track} ${wheel_center_z}" rpy="0 0 0"/>
    <axis xyz="0 0 1"/>
    <limit lower="${-steering_limit}" upper="${steering_limit}" effort="100" velocity="1.5"/>
    <dynamics damping="0.15" friction="0.02"/>
  </joint>

  <joint name="front_right_steering_joint" type="revolute">
    <parent link="base_link"/>
    <child link="front_right_steering_link"/>
    <origin xyz="${front_axle_x} ${-half_track} ${wheel_center_z}" rpy="0 0 0"/>
    <axis xyz="0 0 1"/>
    <limit lower="${-steering_limit}" upper="${steering_limit}" effort="100" velocity="1.5"/>
    <dynamics damping="0.15" friction="0.02"/>
  </joint>

</robot>

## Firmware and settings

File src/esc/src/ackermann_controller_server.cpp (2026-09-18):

#include <geometry_msgs/msg/twist.hpp>
#include <nav_msgs/msg/odometry.hpp>
#include <rclcpp/rclcpp.hpp>
#include <rcl_interfaces/msg/set_parameters_result.hpp>
#include <sensor_msgs/msg/imu.hpp>
#include <std_msgs/msg/bool.hpp>
#include <std_msgs/msg/float64.hpp>
#include <std_msgs/msg/float64_multi_array.hpp>
#include <std_msgs/msg/string.hpp>
#include <std_msgs/msg/u_int8_multi_array.hpp>

#include <algorithm>
#include <array>
#include <atomic>
#include <cerrno>
#include <chrono>
#include <cctype>
#include <cmath>
#include <cstdint>
#include <cstring>
#include <deque>
#include <filesystem>
#include <fcntl.h>
#include <functional>
#include <memory>
#include <mutex>
#include <sstream>
#include <stdexcept>
#include <string>
#include <termios.h>
#include <sys/ioctl.h>
#include <thread>
#include <unistd.h>
#include <vector>

using namespace std::chrono_literals;
namespace fs = std::filesystem;

namespace {
constexpr double kPi = 3.14159265358979323846;
constexpr std::uint8_t kSof0 = 0xA5;
constexpr std::uint8_t kSof1 = 0x5A;
constexpr std::uint8_t kVersion = 0x01;
constexpr std::uint8_t kTypeCommand = 0x01;
constexpr std::uint8_t kTypeAck = 0x81;
constexpr std::uint8_t kFlagEstop = 0x01;
constexpr std::size_t kFrameSize = 14;
constexpr std::uint8_t kVescGetValues = 4;
constexpr std::uint8_t kVescGetValuesSelective = 50;
constexpr std::uint32_t kRuntimeValuesMask =
  (1U << 0U) | (1U << 2U) | (1U << 3U) | (1U << 4U) | (1U << 5U) |
  (1U << 6U) | (1U << 7U) | (1U << 8U) | (1U << 15U) | (1U << 16U) | (1U << 17U);
constexpr std::uint8_t kVescSetCurrent = 6;
constexpr std::uint8_t kVescSetErpm = 8;
constexpr std::uint8_t kVescSetPos = 9;
constexpr std::uint8_t kVescCustomAppData = 36;
constexpr std::uint8_t kHbMagic0 = 0x48;
constexpr std::uint8_t kHbMagic1 = 0x42;
constexpr std::uint8_t kHbVersion = 2;
constexpr std::uint8_t kHbGetSteeringCal = 10;
constexpr std::uint8_t kVescForwardCan = 34;
constexpr std::uint8_t kVescRightMotorId = 2;

rclcpp::QoS stateQos()
{
  return rclcpp::QoS(rclcpp::KeepLast(1)).reliable().transient_local();
}

bool finiteTwist(const geometry_msgs::msg::Twist & msg)
{
  return std::isfinite(msg.linear.x) && std::isfinite(msg.angular.z);
}

std::uint16_t crc16Ccitt(const std::uint8_t * data, std::size_t len)
{
  std::uint16_t crc = 0xFFFFU;
  for (std::size_t i = 0; i < len; ++i) {
    crc ^= static_cast<std::uint16_t>(data[i]) << 8U;
    for (int bit = 0; bit < 8; ++bit) {
      crc = (crc & 0x8000U) != 0U
        ? static_cast<std::uint16_t>((crc << 1U) ^ 0x1021U)
        : static_cast<std::uint16_t>(crc << 1U);
    }
  }
  return crc;
}

void writeU16Le(std::uint8_t * p, std::uint16_t value)
{
  p[0] = static_cast<std::uint8_t>(value & 0xFFU);
  p[1] = static_cast<std::uint8_t>((value >> 8U) & 0xFFU);
}

std::uint16_t vescCrc16(const std::uint8_t *data, std::size_t len)
{
  std::uint16_t crc = 0U;
  for (std::size_t i = 0; i < len; ++i) {
    crc ^= static_cast<std::uint16_t>(data[i]) << 8U;
    for (int bit = 0; bit < 8; ++bit) {
      crc = (crc & 0x8000U) != 0U
        ? static_cast<std::uint16_t>((crc << 1U) ^ 0x1021U)
        : static_cast<std::uint16_t>(crc << 1U);
    }
  }
  return crc;
}

void appendI32Be(std::vector<std::uint8_t> &out, std::int32_t value)
{
  const auto u = static_cast<std::uint32_t>(value);
  out.push_back(static_cast<std::uint8_t>(u >> 24U));
  out.push_back(static_cast<std::uint8_t>(u >> 16U));
  out.push_back(static_cast<std::uint8_t>(u >> 8U));
  out.push_back(static_cast<std::uint8_t>(u));
}

std::int16_t readI16Be(const std::uint8_t *p)
{
  return static_cast<std::int16_t>(
    static_cast<std::uint16_t>(static_cast<std::uint16_t>(p[0]) << 8U) |
    static_cast<std::uint16_t>(p[1]));
}

std::int32_t readI32Be(const std::uint8_t *p)
{
  const std::uint32_t u =
    (static_cast<std::uint32_t>(p[0]) << 24U) |
    (static_cast<std::uint32_t>(p[1]) << 16U) |
    (static_cast<std::uint32_t>(p[2]) << 8U) |
    static_cast<std::uint32_t>(p[3]);
  return static_cast<std::int32_t>(u);
}

std::vector<std::uint8_t> makeVescFrame(const std::vector<std::uint8_t> &payload)
{
  std::vector<std::uint8_t> frame;
  if (payload.empty() || payload.size() > 65535U) return frame;
  if (payload.size() <= 255U) {
    frame.reserve(payload.size() + 5U);
    frame.push_back(2U);
    frame.push_back(static_cast<std::uint8_t>(payload.size()));
  } else {
    frame.reserve(payload.size() + 6U);
    frame.push_back(3U);
    frame.push_back(static_cast<std::uint8_t>(payload.size() >> 8U));
    frame.push_back(static_cast<std::uint8_t>(payload.size()));
  }
  frame.insert(frame.end(), payload.begin(), payload.end());
  const std::uint16_t crc = vescCrc16(payload.data(), payload.size());
  frame.push_back(static_cast<std::uint8_t>(crc >> 8U));
  frame.push_back(static_cast<std::uint8_t>(crc));
  frame.push_back(3U);
  return frame;
}

std::vector<std::uint8_t> wrapRightMotor(const std::vector<std::uint8_t> &inner)
{
  std::vector<std::uint8_t> payload;
  payload.reserve(inner.size() + 2U);
  payload.push_back(kVescForwardCan);
  payload.push_back(kVescRightMotorId);
  payload.insert(payload.end(), inner.begin(), inner.end());
  return payload;
}

std::uint16_t readU16Le(const std::uint8_t * p)
{
  return static_cast<std::uint16_t>(p[0]) |
         static_cast<std::uint16_t>(static_cast<std::uint16_t>(p[1]) << 8U);
}

std::int16_t readI16Le(const std::uint8_t * p)
{
  return static_cast<std::int16_t>(readU16Le(p));
}

}  // namespace

class EscAckermann final : public rclcpp::Node
{
public:
  EscAckermann()
  : Node("esc_ackermann")
  {
    declareParameters();
    readParameters();
    parameter_callback_handle_ = add_on_set_parameters_callback(
      std::bind(&EscAckermann::onRuntimeParameters, this, std::placeholders::_1));
    createInterfaces();

    if (serial_enabled_ && transport_mode_ == "direct_vesc") startSerialThread();

    RCLCPP_INFO(get_logger(), "[ESC] Ackermann controller ready | calibrated CMD/FB topics + direct calibration jog enabled");
    RCLCPP_INFO(
      get_logger(),
      "ESC Ackermann integrated | priority TELEOP > NAV2 > IDLE | teleop=%s nav2=%s | transport=%s endpoint=%s",
      teleop_topic_.c_str(), nav2_topic_.c_str(), transport_mode_.c_str(),
      serial_device_.empty() ? "AUTO" : serial_device_.c_str());
    RCLCPP_INFO(
      get_logger(),
      "Drive conversion: speed +/-%.3f m/s <-> VESC +/-%.1f eRPM (%.3f eRPM/(m/s)); "
      "native direct VESC | steering +/-%.1f deg | teleop yaw +/-%.1f deg/s",
      speed_max_mps_, speed_max_mps_ * driveErpmPerMps(), driveErpmPerMps(),
      steering_max_deg_, yaw_max_deg_s_);
    RCLCPP_INFO(
      get_logger(),
      "Steering feedback calibration: %s | CMD L/C/R=%+.3f/%+.3f/%+.3f deg | FB L/C/R=%+.3f/%+.3f/%+.3f deg | "
      "direct_mode=%s limit=%.1fdeg | saved=%s",
      (steering_feedback_calibration_enabled_ && steering_feedback_calibration_valid_) ? "ACTIVE" : "OFF",
      steering_feedback_left_stop_deg_, steering_feedback_center_deg_, steering_feedback_right_stop_deg_,
      steering_feedback_left_reference_deg_, steering_feedback_center_reference_deg_, steering_feedback_right_reference_deg_,
      steering_calibration_mode_enabled_ ? "ON" : "OFF", steering_calibration_direct_limit_deg_,
      steering_feedback_calibration_saved_at_.empty() ? "-" : steering_feedback_calibration_saved_at_.c_str());
    RCLCPP_INFO(
      get_logger(),
      "Steering PHYSICAL Part1: %s | wheel L/R=%+.2f/%+.2f deg | operational +/-%.2f deg | saved=%s",
      (steering_physical_calibration_enabled_ && steering_physical_calibration_valid_) ? "ACTIVE" : "NOT-CALIBRATED",
      steering_physical_left_limit_deg_, steering_physical_right_limit_deg_,
      operationalPhysicalLimitDeg(),
      steering_physical_calibration_saved_at_.empty() ? "-" : steering_physical_calibration_saved_at_.c_str());
    RCLCPP_INFO(
      get_logger(),
      "Steering center lock: %s | request<=%.2fdeg capture<=%.1fdeg fb_deadband=%.2fdeg "
      "P=%.2f adapt=%.2f/s max_trim=%.1fdeg trim_rate=%.1fdeg/s latch=%s",
      steering_center_hold_enabled_ ? "ON" : "OFF", steering_center_hold_request_deadband_deg_,
      steering_center_hold_capture_deg_, steering_center_hold_feedback_deadband_deg_,
      steering_center_hold_kp_, steering_center_hold_adapt_gain_per_sec_, steering_center_hold_max_trim_deg_,
      steering_center_hold_trim_rate_deg_s_,
      steering_center_hold_latch_inside_deadband_ ? "ON" : "OFF");
  }

  ~EscAckermann() override
  {
    requestSafeShutdown();
    stopSerialThread();
  }

  // Called from rclcpp::on_shutdown as soon as SIGINT/SIGTERM is observed.
  // Keep this callback lock-free/non-blocking: the serial worker performs the
  // bounded final safe-stop burst and owns the file descriptor close.
  void requestSafeShutdown() noexcept
  {
    safe_stop_requested_.store(true);
    serial_thread_running_.store(false);
  }

private:
  struct Sample
  {
    geometry_msgs::msg::Twist cmd{};
    rclcpp::Time received{0, 0, RCL_ROS_TIME};
    bool valid{false};
  };

  struct Selected
  {
    geometry_msgs::msg::Twist twist{};
    std::string source{"IDLE"};
    bool estop{false};
    bool teleop{false};
    bool nav2{false};
  };

  struct SerialCommand
  {
    std::int16_t left_cdeg{0};       // legacy frame only; physical steering deg x100
    double left_vesc_pos_deg{180.0}; // native VESC LEFT actuator coordinate 0..360
    bool left_position_active{false};  // false = torque-off LEFT; prevents idle startup buzz
    std::int16_t right_erpm_x10{0};  // legacy direct-serial frame only
    double stm32_right_erpm{0.0};   // native VESC COMM_SET_RPM; no int16 truncation
    std::uint8_t flags{0};
  };

  void declareParameters()
  {
    declare_parameter<std::string>("teleop_topic", "/cmd_vel/teleop");
    declare_parameter<std::string>("teleop_source_topic", "/teleop/active_source");
    declare_parameter<std::string>("router_source_topic", "/navigation/cmd_mux/source");
    declare_parameter<std::string>("teleop_estop_topic", "/teleop/emergency_stop_latched");
    declare_parameter<std::string>("hmi_topic", "/hmi/cmd_vel");
    declare_parameter<std::string>("hmi_source_topic", "/hmi/active_source");
    declare_parameter<double>("hmi_timeout_sec", 0.30);
    declare_parameter<std::string>("nav2_topic", "/cmd_vel");
    declare_parameter<std::string>("output_topic", "/cmd_vel/actuator");
    declare_parameter<std::string>("active_source_topic", "/esc/mux/active_source");
    declare_parameter<std::string>("autonomy_gate_topic", "/system/autonomy_motion_allowed");
    declare_parameter<std::string>("global_estop_topic", "/safety/estop");
    declare_parameter<std::string>("maintenance_owner_topic", "/esc/vesc/maintenance_owner");
    declare_parameter<std::string>("perception_state_topic", "/navigation/trajectory_safety_state");

    declare_parameter<double>("command_rate_hz", 50.0);
    declare_parameter<double>("teleop_timeout_sec", 0.30);
    declare_parameter<double>("nav2_timeout_sec", 0.60);
    declare_parameter<double>("perception_state_timeout_sec", 0.75);
    declare_parameter<double>("manual_release_hold_sec", 1.00);
    declare_parameter<bool>("require_autonomy_gate", true);
    declare_parameter<bool>("raw_commissioning_enabled", false);
    declare_parameter<std::string>("raw_commissioning_topic", "/esc/commissioning/raw_actuator");
    declare_parameter<double>("raw_commissioning_timeout_sec", 0.25);
    declare_parameter<double>("raw_commissioning_max_erpm", 8000.0);
    declare_parameter<double>("raw_commissioning_max_steering_deg", 30.0);

    // Injected by esc.launch.py from the single esc/config/teleop.yaml source of truth.
    declare_parameter<double>("speed_max", 0.5);
    declare_parameter<double>("manual_speed_max_mps", 1.0);
    declare_parameter<double>("yaw_max_deg_s", 80.0);
    declare_parameter<double>("serial_left_max_deg", 90.0);
    // Single longitudinal calibration authority: VESC electrical speed <-> ground speed.
    // Nav2 remains SI (m/s); VESC remains eRPM. N2.1 updates this value directly.
    declare_parameter<double>("drive_erpm_per_mps", 8000.0);
    // Hard actuator-boundary clamp applied AFTER source mux. This is the single
    // eRPM authority for commissioning and low-speed validation.
    declare_parameter<bool>("drive_erpm_lock_enabled", false);
    declare_parameter<double>("drive_erpm_lock_abs", 8000.0);
    // Command-side quiet band around zero. Requests smaller than this are
    // forced to an exact 0 eRPM before reaching the VESC speed PID. This
    // prevents joystick/Nav2 numerical noise from exciting Hall-speed hunting.
    declare_parameter<double>("drive_zero_command_deadband_erpm", 75.0);
    declare_parameter<double>("zero_hold_feedback_deadband_erpm", 1100.0);
    declare_parameter<int>("zero_hold_feedback_release_samples", 3);
    declare_parameter<double>("wheelbase_m", 0.70);
    declare_parameter<double>("track_width_m", 0.48);
    declare_parameter<double>("min_speed_for_nav_steering_mps", 0.05);

    // PX4-rover-inspired lower-level yaw-rate feedback. The existing Ackermann
    // geometry remains the feed-forward term; this PI only corrects model/steering
    // error during forward NAV2 motion using fresh REP-103 IMU gyro-Z.
    declare_parameter<bool>("yaw_rate_feedback_enabled", true);
    declare_parameter<std::string>("yaw_rate_feedback_imu_topic", "/imu/data");
    declare_parameter<double>("yaw_rate_feedback_kp_deg_per_rps", 2.0);
    declare_parameter<double>("yaw_rate_feedback_ki_deg_per_rad", 0.30);
    declare_parameter<double>("yaw_rate_feedback_integral_limit_deg", 2.0);
    declare_parameter<double>("yaw_rate_feedback_correction_limit_deg", 4.0);
    declare_parameter<double>("yaw_rate_feedback_timeout_sec", 0.25);
    declare_parameter<double>("yaw_rate_feedback_min_speed_mps", 0.10);
    declare_parameter<double>("yaw_rate_setpoint_slew_rps2", 1.0);
    declare_parameter<double>("yaw_rate_feedback_deadband_rps", 0.01);

    declare_parameter<bool>("invert_steering", false);
    declare_parameter<bool>("invert_drive", false);

    // ROS owns the vehicle-angle calibration. F103/VESC remains in a raw
    // 0..360 LEFT actuator coordinate. These are the raw VESC POS readings that
    // correspond to physical -operational/0/+operational wheel angles. Defaults
    // implement the canonical -30/0/+30 -> 0/180/360 mapping.
    declare_parameter<double>("steering_vesc_pos_left_deg", 0.0);
    declare_parameter<double>("steering_vesc_pos_center_deg", 180.0);
    declare_parameter<double>("steering_vesc_pos_right_deg", 360.0);
    declare_parameter<double>("steering_vesc_pos_reference_deg", 30.0);
    declare_parameter<std::string>("steering_vesc_pos_calibration_saved_at", "");

    // Persistent 3-point feedback calibration written by the GUI. The stored
    // readings use the legacy/un-calibrated steering convention after
    // invert_steering is applied, so the values match the old GUI display.
    declare_parameter<bool>("steering_feedback_calibration_enabled", false);
    declare_parameter<double>("steering_feedback_center_deg", 0.0);
    declare_parameter<double>("steering_feedback_right_stop_deg", 90.0);
    declare_parameter<double>("steering_feedback_left_stop_deg", -90.0);
    // Backward-compatible parameter only. Runtime uses independently captured RIGHT
    // and LEFT points directly; do not force equal raw encoder spans because the
    // steering linkage can have different transfer ratios on each side.
    declare_parameter<bool>("steering_feedback_force_symmetric_span", false);
    // Suppress tiny feedback/encoder jitter around the calibrated straight-ahead
    // position so odometry does not integrate a false yaw while driving straight.
    declare_parameter<double>("steering_straight_deadband_deg", 1.0);
    // Direction-dependent return error (backlash/static friction) can leave the
    // feedback on a different side of CENTER after a left vs right turn. When
    // the requested vehicle steering is straight, apply a small outer feedback
    // trim to the raw STM position command once the mechanism is near center.
    declare_parameter<bool>("steering_center_hold_enabled", true);
    declare_parameter<double>("steering_center_hold_request_deadband_deg", 0.75);
    declare_parameter<double>("steering_center_hold_capture_deg", 20.0);
    declare_parameter<double>("steering_center_hold_feedback_deadband_deg", 0.35);
    declare_parameter<double>("steering_center_hold_kp", 0.25);
    declare_parameter<double>("steering_center_hold_adapt_gain_per_sec", 1.50);
    // Deprecated compatibility parameters. Center hold intentionally has no integral term.
    declare_parameter<double>("steering_center_hold_ki", 0.0);
    declare_parameter<double>("steering_center_hold_integral_limit_deg_s", 0.0);
    declare_parameter<double>("steering_center_hold_max_trim_deg", 12.0);
    declare_parameter<double>("steering_center_hold_trim_rate_deg_s", 60.0);
    declare_parameter<bool>("steering_center_hold_latch_inside_deadband", true);
    declare_parameter<double>("steering_center_hold_feedback_timeout_sec", 0.30);
    declare_parameter<double>("diagnostic_trace_hz", 2.0);
    declare_parameter<std::string>("steering_feedback_calibration_saved_at", "");
    // The GUI writes a one-shot token with each atomic apply. Older runtimes that do
    // not declare this parameter cannot falsely report
    // that a live calibration was applied.
    declare_parameter<std::string>("steering_calibration_apply_token", "");

    // ROS-only measured calibration. The existing STM firmware remains protocol V1
    // (-90..+90 degrees). GUI capture stores BOTH the protocol command that placed the
    // wheel and the protocol feedback measured at that physical reference point.
    declare_parameter<bool>("steering_calibration_mode_enabled", false);
    declare_parameter<double>("steering_calibration_direct_limit_deg", 90.0);
    declare_parameter<double>("steering_feedback_left_reference_deg", -80.0);
    declare_parameter<double>("steering_feedback_center_reference_deg", 0.0);
    declare_parameter<double>("steering_feedback_right_reference_deg", 80.0);

    // Physical calibration: protocol -90/0/+90 is NOT a physical wheel angle. These
    // parameters are measured wheel angles relative to a physically straight
    // wheel. LEFT is negative and RIGHT is positive in the vehicle convention.
    // The operational limit is deliberately symmetric and must not exceed the
    // smaller measured mechanical side. It is what Teleop/Nav2 are allowed to request.
    declare_parameter<bool>("steering_physical_calibration_enabled", false);
    declare_parameter<double>("steering_physical_left_limit_deg", -30.0);
    declare_parameter<double>("steering_physical_right_limit_deg", 30.0);
    declare_parameter<double>("steering_physical_operational_limit_deg", 30.0);
    declare_parameter<std::string>("steering_physical_calibration_saved_at", "");

    // Multi-point physical steering LUT. Physical angles are strictly
    // increasing LEFT(negative) -> RIGHT(positive). Separate increasing and
    // decreasing sweeps preserve linkage hysteresis/backlash. The three-point
    // Part-1 calibration remains the fail-safe fallback when this LUT is disabled.
    declare_parameter<bool>("steering_physical_lut_enabled", false);
    declare_parameter<std::vector<double>>("steering_lut_physical_deg", {-30.0, 0.0, 30.0});
    declare_parameter<std::vector<double>>("steering_lut_command_increasing_deg", {-90.0, 0.0, 90.0});
    declare_parameter<std::vector<double>>("steering_lut_command_decreasing_deg", {-90.0, 0.0, 90.0});
    declare_parameter<std::vector<double>>("steering_lut_feedback_increasing_deg", {-90.0, 0.0, 90.0});
    declare_parameter<std::vector<double>>("steering_lut_feedback_decreasing_deg", {-90.0, 0.0, 90.0});
    declare_parameter<double>("steering_lut_direction_deadband_deg", 0.15);
    declare_parameter<std::string>("steering_lut_calibration_saved_at", "");

    declare_parameter<double>("steering_center_bias_from_left_deg", 0.0);
    declare_parameter<double>("steering_center_bias_from_right_deg", 0.0);

    // Production architecture: package esc owns the F103 USB-UART directly. F411/stmf4
    // is sensor/HMI-only and must never carry actuator bytes.
    declare_parameter<std::string>("transport_mode", "direct_vesc");
    // Keep the ROS control/localization stack alive when the actuator transport is
    // intentionally disabled. Disabled never means READY; it only suppresses TX/open/retry.
    declare_parameter<bool>("serial_enabled", true);
    // Explicit bench/integration mode for navigation qualification without an ESC.
    // This mode hard-disables the physical UART and publishes a zero-motion odometry
    // heartbeat. Physical /esc/ready and /esc/feedback_valid remain FALSE.
    declare_parameter<bool>("integration_bypass", false);
    declare_parameter<std::string>("serial_device", "auto");
    declare_parameter<std::string>(
      "serial_auto_id_contains", "1a86_USB_Serial");
    // Current ESC UART is the verified QinHeng CH340 (1a86:7523). Unique by-id is the
    // primary selector; physical topology is only a deterministic fallback.
    declare_parameter<std::string>("serial_auto_path_contains", "");
    declare_parameter<int>("serial_baud", 921600);
    declare_parameter<double>("serial_tx_rate_hz", 50.0);
    declare_parameter<double>("serial_reconnect_sec", 0.25);
    declare_parameter<double>("serial_ack_timeout_sec", 0.60);
    declare_parameter<double>("command_watchdog_sec", 0.25);
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
int main(int argc, char ** argv)
{
  rclcpp::init(argc, argv);
  auto node = std::make_shared<EscAckermann>();
  std::weak_ptr<EscAckermann> weak_node = node;
  rclcpp::on_shutdown([weak_node]() {
    if (auto locked = weak_node.lock()) locked->requestSafeShutdown();
  });
  rclcpp::spin(node);
  node->requestSafeShutdown();
  node.reset();
  if (rclcpp::ok()) rclcpp::shutdown();
  return 0;
}

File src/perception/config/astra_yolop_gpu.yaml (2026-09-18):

perception:
  ros__parameters:
    perception_mode: 'off'
    inference_enabled: false
    engine_path: models/yolopv2.engine
    pt_model_path: auto
    gpu_device: 0
    cpu_inference_fps: 2.0
    cpu_threads: 3
    opencv_threads: 1
    torch_optimize_for_inference: true
    cpu_emergency_stop_distance_m: 0.65
    cpu_emergency_half_width_m: 0.55
    rgb_device: auto
    rgb_width: 1280
    rgb_height: 720
    fps: 30
    allow_resolution_fallback_for_fps: false
    strict_camera_mode: false
    camera_hotplug_retry: true
    camera_retry_interval_sec: 2.0
    camera_read_fail_threshold: 5
    camera_online_good_frames: 3
    camera_block_watchdog_sec: 2.5
    camera_retry_log_interval_sec: 30.0
    v4l2_pixel_format: MJPEG
    allow_mjpeg_cpu_fallback: true
    use_v4l2_userptr_zero_copy: false
    v4l2_buffer_count: 3
    flip_horizontal: true
    confidence_threshold: 0.1
    iou_threshold: 0.45
    max_candidates: 16384
    max_detections: 300
    warmup_iterations: 5
    lane_threshold: 0.5
    overlay_alpha: 0.25
    box_thickness: 2
    draw_text_labels_cpu: false
    publish_annotated: true
    publish_raw_rgb: true
    publish_masks: false
    publish_drivable_mask: false
    publish_lane_mask: true
    publish_class_mask: false
    publish_detections: true
    publish_lane_metrics: true
    publish_obstacle_metrics: true
    publish_only_when_subscribed: true
    async_rviz_publish: true
    publisher_reliability: reliable
    rviz_publish_buffer_count: 2
    rviz_max_publish_rate_hz: 10.0
    web_preview_enabled: true
    web_preview_fps: 10.0
    web_preview_width: 640
    web_preview_height: 360
    web_preview_jpeg_quality: 70
    web_preview_topic: /camera/astra/image_preview/compressed
    show_opencv_cuda_window: false
    opencv_use_cuda_opengl: true
    opencv_window_width: 640
    opencv_window_height: 480
    opencv_window_fullscreen: false
    frame_id: camera_color_optical_frame
    annotated_topic: /camera/yolop/image_annotated
    drivable_mask_topic: /yolop/drivable_mask
    lane_mask_topic: /yolop/lane_mask
    raw_topic: /camera/astra/image_raw
    camera_info_topic: /camera/color/camera_info
    detections_topic: /yolop/detections
    lane_metrics_topic: /yolop/lane_metrics
    drivable_space_topic: /perception/drivable_space
    drivable_boundary_points_topic: /perception/drivable_boundary_points
    obstacle_metrics_topic: /yolop/obstacle_metrics_raw
    performance_topic: /perception/performance
    metric_frame_id: base_footprint
    class_mask_topic: /yolop/class_mask
    ground_calibration_width: 1280
    ground_calibration_height: 720
    ground_src_points:
    - 40.0
    - 680.0
    - 1240.0
    - 680.0
    - 760.0
    - 350.0
    - 520.0
    - 350.0
    ground_dst_points:
    - 0.0
    - 513.5714111
    - 1279.0
    - 503.2999878
    - 1279.0
    - 10.2714281
    - 0.0
    - 0.0
    ground_canvas_width: 1280
    ground_canvas_height: 720
    ground_origin_x_px: 596.8666667
    ground_origin_y_px: 719.0
    ground_meters_per_pixel_x: 0.003909304143862393
    ground_meters_per_pixel_y: 0.009735744089012517
    metric_forward_offset_m: 0.0
    metric_lateral_offset_m: 0.0
    metric_minimum_forward_m: 0.2
    metric_maximum_forward_m: 4.0
    metric_maximum_abs_left_m: 2.5
    lane_vehicle_width_m: 0.55
    lane_minimum_road_width_m: 3.5
    lane_maximum_road_width_m: 6.5
    lane_lookahead_near_m: 1.0
    lane_lookahead_far_m: 3.0
    lane_control_lookahead_m: 2.0
    lane_sample_rows: 72
    lane_minimum_valid_rows: 18
    lane_minimum_center_offset_m: 0.08
    lane_ema_alpha: 0.35
    drivable_space_near_m: 0.35
    drivable_space_far_m: 4.0
    drivable_space_max_abs_left_m: 2.8
    drivable_space_sample_rows: 64
    drivable_space_min_pixels_per_row: 8
    drivable_space_pixel_stride_px: 4
    drivable_boundary_guard_offset_m: 0.0
    drivable_boundary_z_m: 0.2
    drivable_lane_constraint_min_confidence: 0.25
    camera_fx: 910.0
    camera_fy: 910.0
    camera_cx: 640.0
    camera_cy: 360.0
    camera_distortion:
    - 0.0
    - 0.0
    - 0.0
    - 0.0
    - 0.0
    enable_integrated_perception_runtime: true
    lane_safety_enabled: false
    # Dua garis safety fisik. Baseline sinkron URDF ADV: total_width=0.550 m,
    # camera ground height = vehicle_top(0.700) + camera offset(0.036) = 0.736 m,
    # camera pitch URDF = 0 deg. fx/fy/cx/cy di bawah merepresentasikan FOV kamera.
    lane_corridor_overlay_enabled: true
    lane_corridor_control_enabled: true
    # Drag/drop ROS Web menyimpan empat endpoint safety line secara normalized.
    lane_corridor_manual_lines_enabled: true
    # Legacy/common overlap used as sampling window. Endpoint Y below are authoritative
    # for the four independently draggable Lane Safety handles.
    lane_corridor_top_y_ratio: 0.7566862890516363
    lane_corridor_bottom_y_ratio: 0.995
    lane_corridor_left_top_x_ratio: 0.4119936758366552
    lane_corridor_left_top_y_ratio: 0.7566862890516363
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

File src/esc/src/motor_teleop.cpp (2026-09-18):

#include <algorithm>
#include <atomic>
#include <cstdint>
#include <cerrno>
#include <cctype>
#include <chrono>
#include <cmath>
#include <cstring>
#include <filesystem>
#include <functional>
#include <fcntl.h>
#include <iomanip>
#include <linux/input.h>
#include <limits.h>
#include <memory>
#include <mutex>
#include <poll.h>
#include <set>
#include <sstream>
#include <stdexcept>
#include <string>
#include <thread>
#include <unordered_map>
#include <utility>
#include <vector>
#include <sys/ioctl.h>
#include <termios.h>
#include <unistd.h>

#include "geometry_msgs/msg/twist.hpp"
#include "rclcpp/rclcpp.hpp"
#include "std_msgs/msg/bool.hpp"
#include "std_msgs/msg/float64_multi_array.hpp"
#include "std_msgs/msg/string.hpp"

using namespace std::chrono_literals;
namespace fs = std::filesystem;

namespace {
constexpr double kPi = 3.14159265358979323846;
constexpr int kBitsPerLong = static_cast<int>(sizeof(unsigned long) * 8U);

struct ControlFractions {
  double forward{0.0};
  double yaw{0.0};
};

double clamp_value(double value, double lo, double hi) {
  return std::max(lo, std::min(value, hi));
}

bool almost_zero(double value, double eps = 1e-6) {
  return std::abs(value) <= eps;
}

std::string real_path(const std::string &path) {
  char buffer[PATH_MAX];
  return ::realpath(path.c_str(), buffer) ? std::string(buffer) : path;
}

std::string lowercase_copy(std::string text) {
  std::transform(text.begin(), text.end(), text.begin(),
                 [](unsigned char c) { return static_cast<char>(std::tolower(c)); });
  return text;
}

bool bit_is_set(const std::vector<unsigned long> &bits, int bit) {
  if (bit < 0) return false;
  const size_t index = static_cast<size_t>(bit / kBitsPerLong);
  if (index >= bits.size()) return false;
  return (bits[index] & (1UL << (bit % kBitsPerLong))) != 0;
}

bool read_event_bits(int fd, int event_type, int max_bit, std::vector<unsigned long> &bits) {
  bits.assign(static_cast<size_t>((max_bit + kBitsPerLong) / kBitsPerLong), 0UL);
  return ::ioctl(fd, EVIOCGBIT(event_type, bits.size() * sizeof(unsigned long)), bits.data()) >= 0;
}

std::string input_device_name(int fd) {
  char name[256] = {};
  if (::ioctl(fd, EVIOCGNAME(sizeof(name)), name) < 0) return "unknown";
  return std::string(name);
}

bool input_device_id(int fd, input_id &id) {
  std::memset(&id, 0, sizeof(id));
  return ::ioctl(fd, EVIOCGID, &id) >= 0;
}

bool input_fd_alive(int fd) {
  input_id id{};
  return input_device_id(fd, id);
}

bool get_abs_info(int fd, int code, input_absinfo &info) {
  std::memset(&info, 0, sizeof(info));
  return code >= 0 && code <= ABS_MAX && ::ioctl(fd, EVIOCGABS(code), &info) >= 0;
}

bool fd_supports_abs(int fd, int code) {
  std::vector<unsigned long> bits;
  return read_event_bits(fd, EV_ABS, ABS_MAX, bits) && bit_is_set(bits, code);
}

bool fd_looks_like_keyboard(int fd) {
  std::vector<unsigned long> key_bits;
  if (!read_event_bits(fd, EV_KEY, KEY_MAX, key_bits)) return false;
  return bit_is_set(key_bits, KEY_W) && bit_is_set(key_bits, KEY_A) &&
         bit_is_set(key_bits, KEY_S) && bit_is_set(key_bits, KEY_D);
}

bool name_looks_like_game_controller(const std::string &name) {
  const std::string n = lowercase_copy(name);
  static constexpr const char *kTokens[] = {
      "gamepad", "joystick", "controller", "xbox", "dualshock", "dualsense",
      "playstation", "shanwan", "asteria", "daxa", "rexus", "tyx"};
  for (const char *token : kTokens) {
    if (n.find(token) != std::string::npos) return true;
  }
  return false;
}

const char *abs_code_name(int code) {
  switch (code) {
    case ABS_X: return "ABS_X";
    case ABS_Y: return "ABS_Y";
    case ABS_Z: return "ABS_Z";
    case ABS_RX: return "ABS_RX";
    case ABS_RY: return "ABS_RY";
    case ABS_RZ: return "ABS_RZ";
    case ABS_HAT0X: return "ABS_HAT0X";
    case ABS_HAT0Y: return "ABS_HAT0Y";
    case ABS_GAS: return "ABS_GAS";
    case ABS_BRAKE: return "ABS_BRAKE";
    default: return "ABS_UNKNOWN";
  }
}

std::string hex4(unsigned int value) {
  std::ostringstream oss;
  oss << std::hex << std::setfill('0') << std::setw(4) << (value & 0xffffU);
  return oss.str();
}

class TerminalEchoGuard {
public:
  bool enable() {
    if (enabled_) return true;
    fd_ = ::open("/dev/tty", O_RDWR | O_NOCTTY | O_CLOEXEC | O_NONBLOCK);
    if (fd_ < 0) return false;
    if (::tcgetattr(fd_, &saved_) != 0) {
      ::close(fd_);
      fd_ = -1;
      return false;
    }
    termios silent = saved_;
    silent.c_lflag &= static_cast<tcflag_t>(~(ECHO | ECHONL));
    if (::tcsetattr(fd_, TCSANOW, &silent) != 0) {
      ::close(fd_);
      fd_ = -1;
      return false;
    }
    enabled_ = true;
    return true;
  }

  void restore() {
    if (!enabled_ || fd_ < 0) return;
    ::tcflush(fd_, TCIFLUSH);
    ::tcsetattr(fd_, TCSANOW, &saved_);
    ::close(fd_);
    fd_ = -1;
    enabled_ = false;
  }

  ~TerminalEchoGuard() { restore(); }

private:
  int fd_{-1};
  bool enabled_{false};
  termios saved_{};
};

}  // namespace
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

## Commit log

2026-09-03 Initial AGV ROS 2 workspace
    [agv.urdf.xacro, atv_rim.stl, bbox_obstacle_calibration.yaml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]
2026-09-03 Harden GNSS IMU ESC USB routing
2026-09-04 perception: replace trapezoid with calibrated safety lines
    [astra_yolop_gpu.yaml]
2026-09-04 fix(nav): calibrate north heading and favor GNSS IMU fusion
    [imu_calibration.yaml]
2026-09-04 fix(field): mirror web camera and avoid ESC restart latch
    [ackermann_controller_server.cpp]
2026-09-04 fix(nav): make GNSS COG authoritative for moving heading
    [ackermann_controller_server.cpp, ekf.yaml, imu.yaml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]
2026-09-04 tune(nav): correct gyro sign and steering center reference
    [ackermann.yaml, imu.yaml]
2026-09-05 docs: record ESC F411/F103 mixed sensor validation
2026-09-05 feat: bridge VESC transport through F411
    [vesc_tool.yaml]
2026-09-05 docs: record left steering encoder calibration audit
2026-09-05 docs: record left steering encoder hardware checkpoint
2026-09-05 docs: record steering detect uart and current fixes
2026-09-05 docs: record clean steering encoder pin baseline
2026-09-05 docs: record zero-span steering encoder sweep
2026-09-05 docs: confirm left hall wiring conflict
2026-09-05 docs: correct steering encoder pull-test diagnosis
2026-09-05 docs: prove steering encoder gpio and tim4 path
2026-09-05 docs: restore legacy left encoder interface
2026-09-05 chore: sync left encoder firmware revision
2026-09-06 fix: harden VESC maintenance and diagnose right motor crosswire
2026-09-08 navigation: validate heading before EKF and harden gyro yaw
2026-09-08 navigation: finalize 8-direction heading calibration
    [heading_8dir_calibration.yaml]
2026-09-08 navigation: align Yahboom IMU frame and raw mag units
2026-09-08 navigation: add CW Yahboom magnetometer auto-fit
2026-09-08 navigation: calibrate Yahboom planar magnetic heading
    [yahboom_mag_calibration.yaml]
2026-09-08 chore: add hoverboard-vesc submodule and update docs
2026-09-12 update F4gateway Stage2 robustness contract
2026-09-14 update F4 gateway robustness and gate stale ESC telemetry
2026-09-14 stage1: fit NEO3 and Yahboom against 360 heading reference
2026-09-14 stage1: capture nine-stop North referenced heading campaign
2026-09-14 stage1: lock heading calibration evidence from runtime apply
2026-09-17 chore: update hoverboard-vesc after v1 merge
2026-09-18 update esc
